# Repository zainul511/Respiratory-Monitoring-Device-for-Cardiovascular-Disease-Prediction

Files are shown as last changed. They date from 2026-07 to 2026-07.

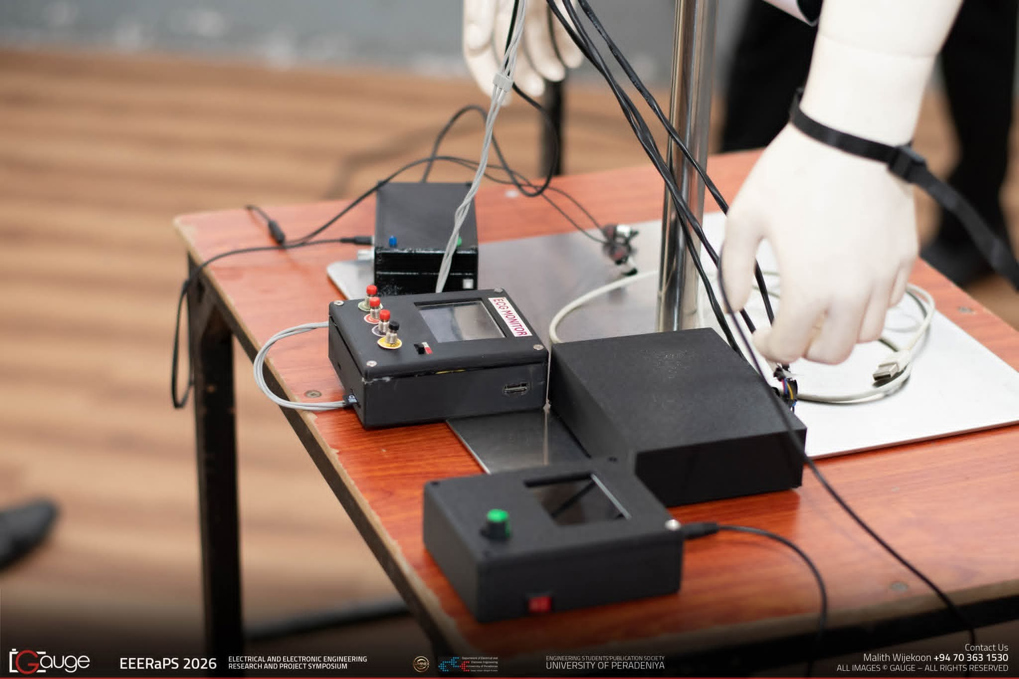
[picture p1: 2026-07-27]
Images/d04af45d-ff1c-4c60-89cd-eda54e68bfce.jpg

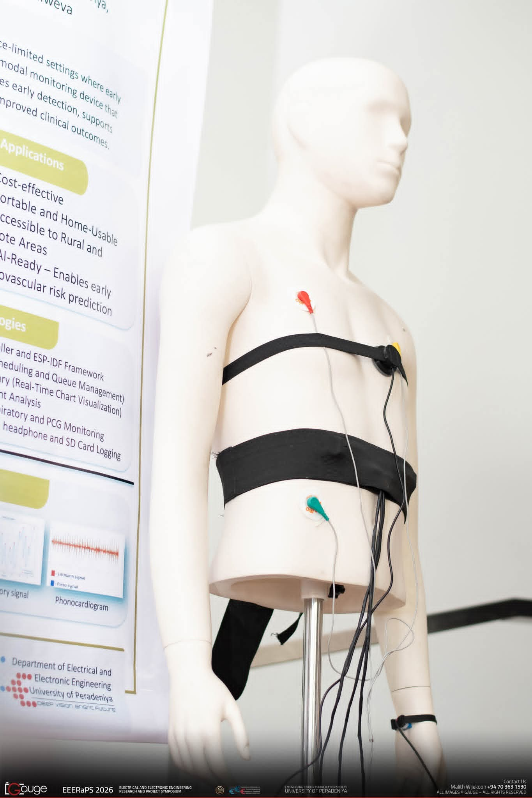
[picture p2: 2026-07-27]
Images/b8c4e4b6-da23-4e0d-b906-4e107dbe2d85.jpg

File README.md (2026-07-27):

# Respiratory-Monitoring-Device-for-Cardiovascular-Disease-Prediction
Wearable respiratory monitor using ESP32 &amp; 3x MPU6050s. Extracts  breathing patterns via Incremental PCA &amp; DMP signal fusion. Includes ESP-IDF firmware (Dual I2C), Code for Python dashboard (PyQt5), and 3D mechanical files for real-time cardiovascular analysis.

##  System Architecture

The device measures chest expansion and contraction using three strategically placed IMUs on a wearable belt. The system is designed to provide  respiratory pattern data through sensor fusion and advanced software processing.

### Key Features
* **Multi-Sensor Fusion:** Utilizes three **MPU6050** accelerometers to capture chest wall movement.
* **Real-Time Visualization:** A  **Python dashboard (PyQt5)** plots breathing waveforms and give visual analysis of respiratory patterns.
* **Advanced Signal Processing:**
    * **Incremental PCA (Principal Component Analysis):** Extracts the dominant breathing motion vector from the 3-axis acceleration data.
    * **EMA (Exponential Moving Average):** Applies smoothing filters to eliminate high-frequency noise and jitter.
* **Wearable Design:** A stretchable belt with  a custom 3D-printed enclosure

## Components Used

| Component | Quantity | Description |
|---|:---:|---|
| ESP32 Development Board | 1 | Main microcontroller (originally ESP32-C3). |
| MPU6050 Sensors | 3 | 6-axis accelerometer/gyroscope modules. |
| Elastic Belt | 1 | 1.5-inch wide stretchable belt with a side-release buckle. |
| JST Connectors | 3 | Detachable connectors for sensor connections. |
| Heat Shrink Tube | – | 1.2 cm diameter tubing for wire insulation and cable management. |
| 3.7 V Li-Po Battery | 1 | Rechargeable lithium-polymer battery for portable power. |
| Boost Converter | 1 | Steps up the battery voltage to the required system voltage. |
| 3.3 V Voltage Regulator | 1 | Provides a stable 3.3 V supply for the ESP32 and sensors. |
| Slide Switch | 1 | Main power ON/OFF switch for the device. |

## 3D Printed Parts

The following custom 3D-printed parts were designed for the wearable system:

- **Enclosure_Box.stl** – Houses the ESP32-C3 and connectors. Includes cutouts for the USB-C port, JST connectors, and the power switch/push button.
- **Bend_on_Belt.stl** – A belt-mounted cable guide that routes sensor wires securely and reduces mechanical stress during movement.

## Technical Implementation

### 1. Sensor Placement & Assembly

- **Three MPU6050 IMUs** are mounted on the elastic belt for respiratory motion sensing.
- **One IMU** is positioned centrally below the chest.
- **Two IMUs** are positioned symmetrically on the left and right sides of the central sensor.
- The sensors are connected using **12 signal lines**:
  - VCC × 3
  - GND × 3
  - SDA × 3
  - SCL × 3
- All wiring is bundled into a **stable cable harness** using heat-shrink tubing to improve mechanical strength, reduce cable movement, and enhance reliability during wearable operation.

## 2. Firmware (ESP-IDF + FreeRTOS)

The firmware is developed using **ESP-IDF** with **FreeRTOS**, providing deterministic task scheduling and reliable acquisition of respiratory motion data from three MPU6050 IMUs at **100 Hz**.

### Method 1 – I²C Multiplexer Architecture

This implementation uses a **PCA9548A I²C multiplexer** to interface with three MPU6050 sensors that all operate at the default **0x68** I²C address. The ESP32 selects the required multiplexer channel before communicating with each sensor.

| Sensor | PCA9548A Channel | I²C Address |
|---|---:|---:|
| IMU 1 | 0 | 0x68 |
| IMU 2 | 1 | 0x68 |
| IMU 3 | 2 | 0x68 |

**Features**
- Single ESP32 hardware I²C bus
- PCA9548A resolves address conflicts
- Sequential sensor polling at **100 Hz**
- Data transmitted to the PC via USB Serial as structured packets

---

### Method 2 – Dual I²C Bus Architecture

This implementation eliminates the external multiplexer by utilizing the ESP32's **two independent hardware I²C controllers**. One bus interfaces with a single MPU6050, while the second bus connects to two MPU6050 sensors configured with different addresses (**0x68** and **0x69**) using the AD0 pin.

| ESP32 I²C Bus | Connected Sensors | I²C Address(es) |
|---|---|---|
| I²C Bus 0 | IMU 1 | 0x68 |
| I²C Bus 1 | IMU 2, IMU 3 | 0x68, 0x69 |

**Features**
- No external I²C multiplexer required
- Reduced hardware complexity and wiring
- Uses both ESP32 hardware I²C peripherals
- **Utilizes the MPU6050 Digital Motion Processor (DMP) for onboard sensor fusion**
- **Obtains gravity-compensated linear acceleration directly from the DMP, reducing software processing on the ESP32**
- Improved signal quality by removing the gravity component before transmission
- Data acquired at **100 Hz** and transmitted via USB Serial as structured packets

## 3. PC Software (Python Dashboard)

The desktop application performs real-time data acquisition, signal processing, visualization, and data logging.

### Data Acquisition

- Reads real-time sensor data from the ESP32 through **USB Serial communication** (`COMx` on Windows).
- Receives linear acceleration data from the three MPU6050 IMU sensors.

### Signal Processing Pipeline

1. **Dimensionality Reduction**
   - Applies **Incremental Principal Component Analysis (IPCA)** to combine 3-axis acceleration data into a single dominant respiratory motion vector.

2. **Signal Smoothing**
   - Uses an **Exponential Moving Average (EMA)** filter to reduce high-frequency noise and improve waveform stability.

3. **Waveform Preservation**
   - Applies a **Besel filter** to remove unwanted frequency components while preserving the respiratory waveform characteristics.

4. **Displacement Estimation**
   - Performs double integration of filtered acceleration data to estimate chest displacement.
   - A low-pass filter(cutoff 0.2Hz) is applied before integration to reduce low-frequency drift caused by sensor bias and integration errors.

### Output

- Real-time visualization of:
  - Respiratory effort waveform
  - Estimated chest displacement waveform

- CSV data logging:
  - Linear acceleration values
  - Extracted respiratory waveform
  - Estimated displacement waveform

 ## Development Challenges & Solutions

### MPU6050 Communication Failure

**Problem:**
- One MPU6050 sensor powered on correctly but failed to transmit data.

**Investigation:**
- Continuity testing revealed a microscopic solder bridge between the pull-up resistors.
- The SDA line was unintentionally shorted to VCC.

**Solution:**
- Removed excess solder and verified the I2C communication.
- The sensor returned to normal operation.

**Lesson Learned:**
- Always verify sensor module connections and perform continuity checks before final assembly.

##  Author

This project was developed as part of an undergraduate final-year engineering project.

- **Subsystem:** Wearable Respiratory Effort Monitoring Device  
- **Main Project:** Pulse-Based Diagnosis System for Cardiovascular Disease Prediction

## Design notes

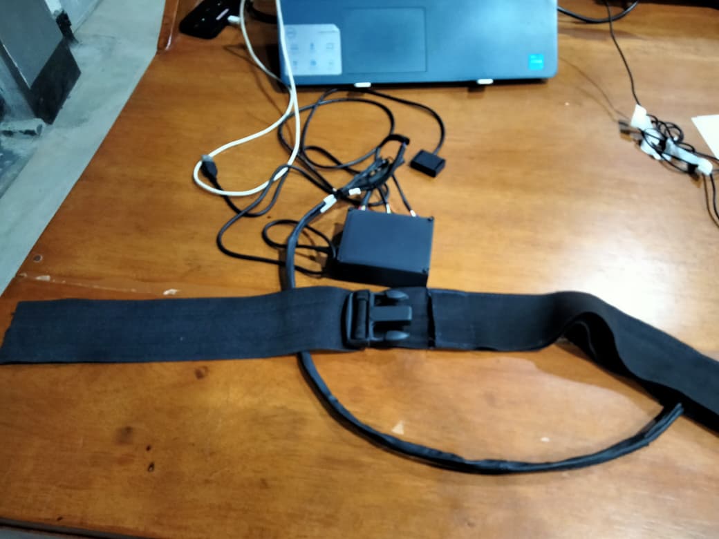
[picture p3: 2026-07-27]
Images/Product.jpeg

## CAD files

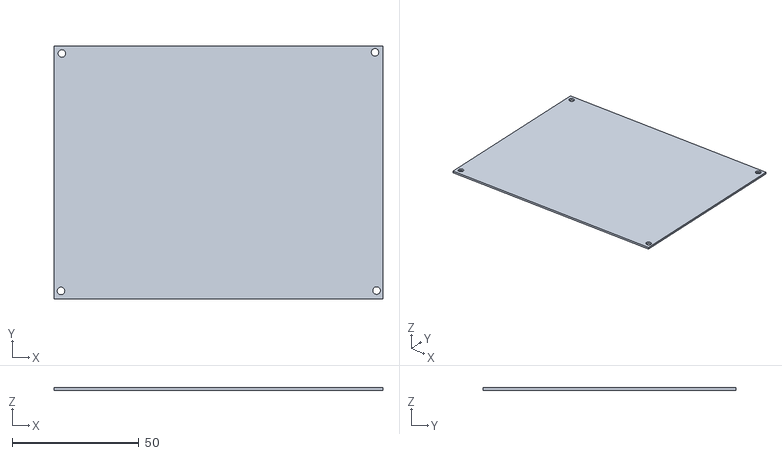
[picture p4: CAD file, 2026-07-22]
3D Printed Parts/lid_of_enclosure_box.stl
130.0 x 100.0 x 1.00

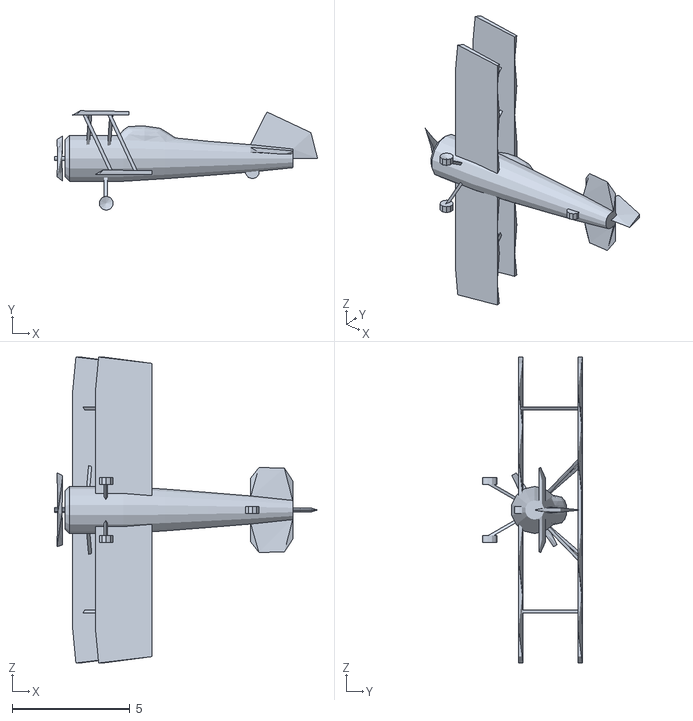
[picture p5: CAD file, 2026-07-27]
Firmware/V1_multiplexer/hello_world/i2cdevlib/Arduino/MPU6050/examples/MPU6050_DMP6_using_DMP_V6.12/MPUplane/data/biplane.obj
11.2 x 4.23 x 13.0

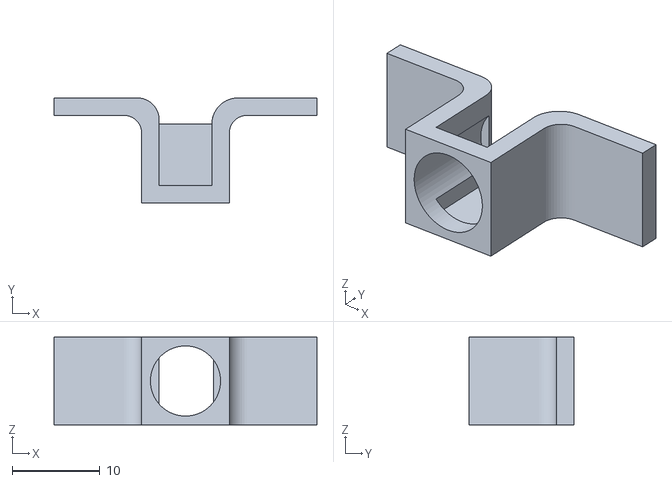
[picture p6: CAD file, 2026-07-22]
3D Printed Parts/Bend_on_Belt.stl
30.0 x 12.0 x 10.0

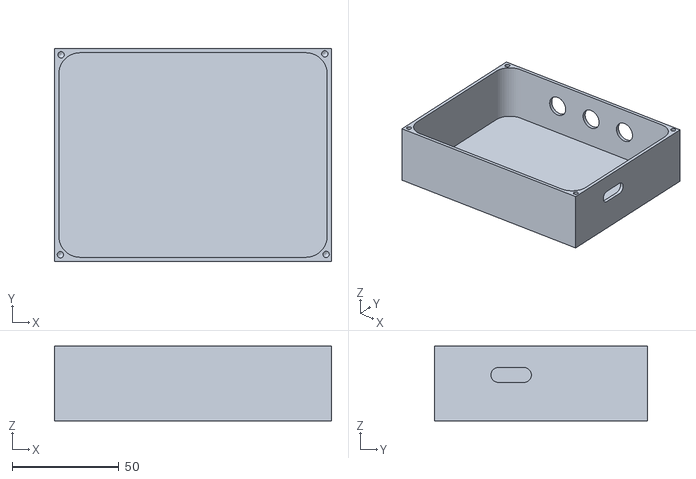
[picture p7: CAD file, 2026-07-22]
3D Printed Parts/Enclosure_Box.stl
130.0 x 100.0 x 35.0

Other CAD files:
Firmware/V1_multiplexer/hello_world/i2cdevlib/PIC18/MPU6050/Examples/MPU6050_raw.X/l.obj

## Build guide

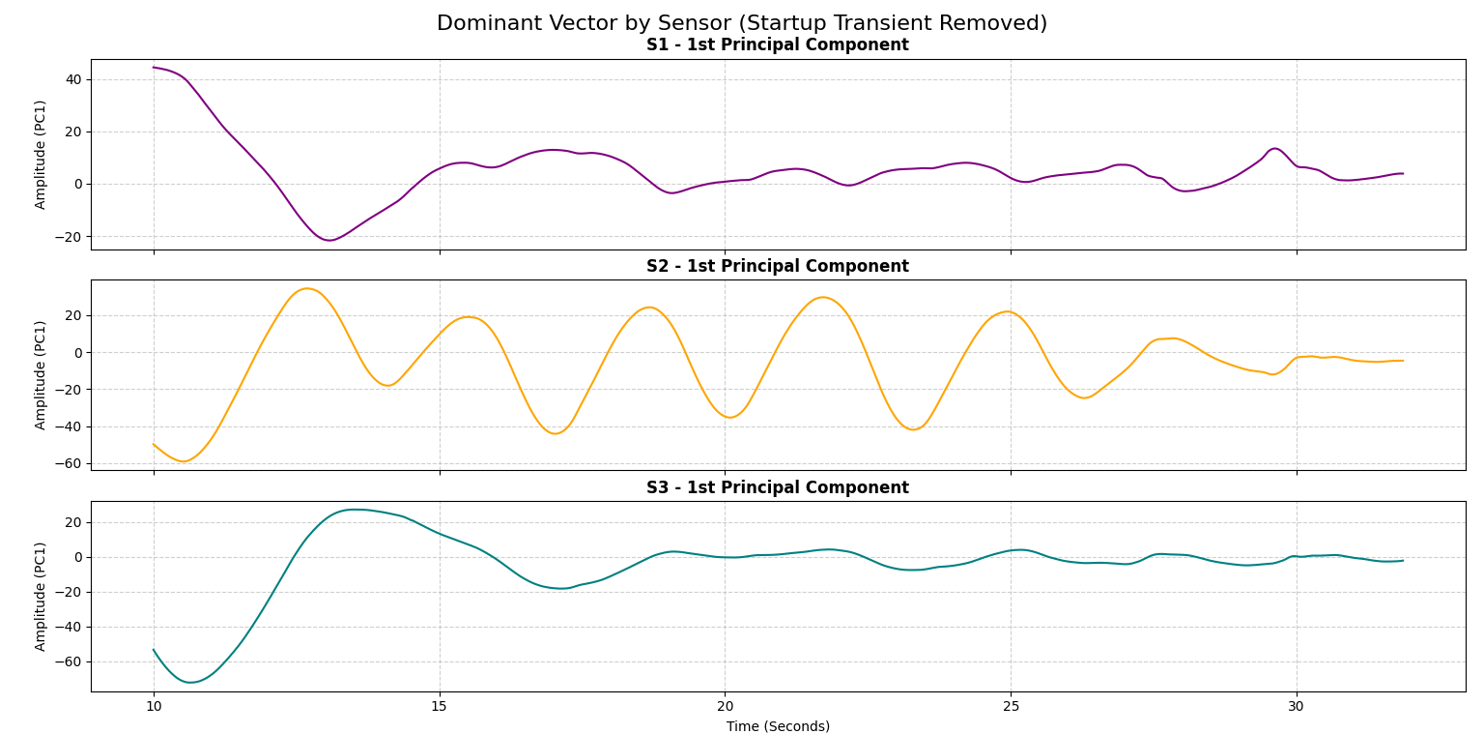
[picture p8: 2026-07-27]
Observations/reconstructed_after_pca.png

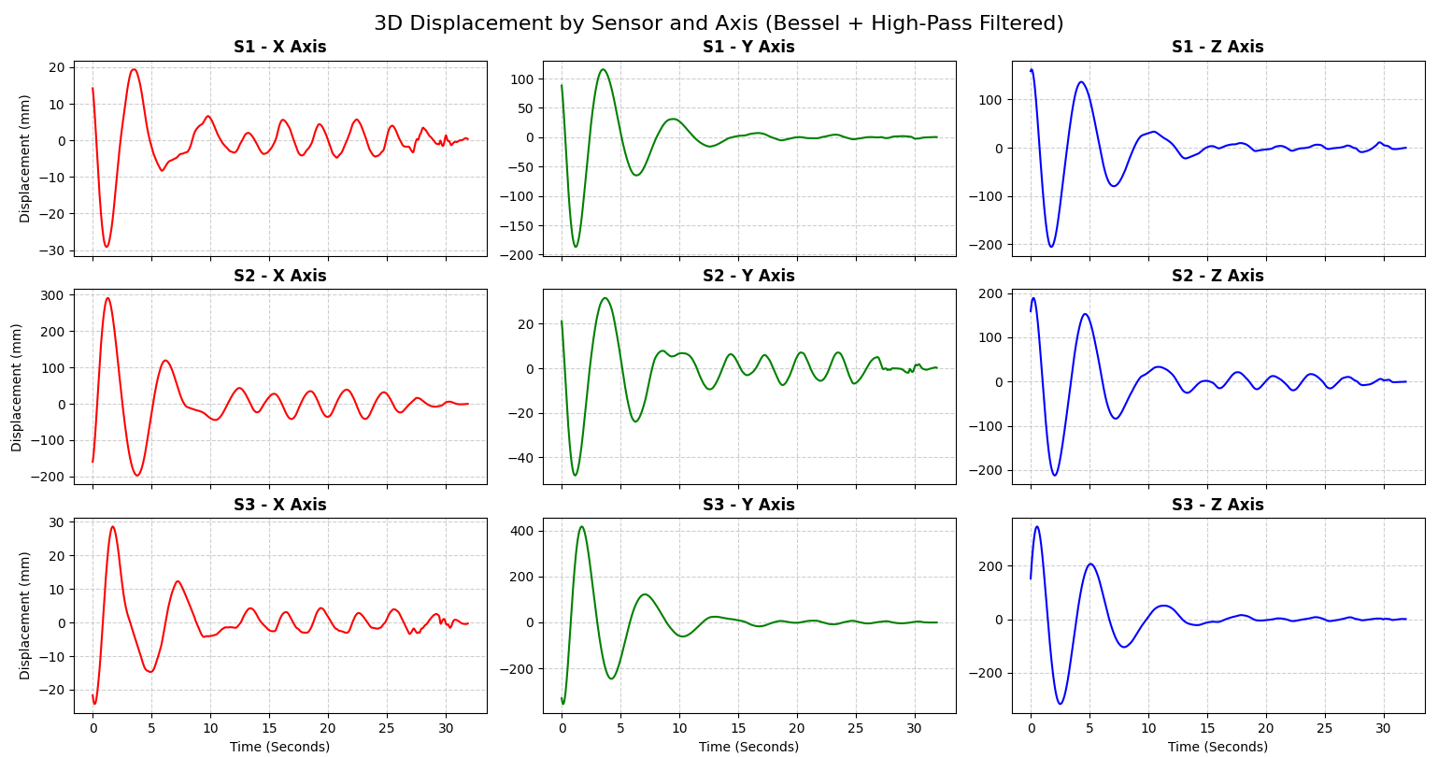
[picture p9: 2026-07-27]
Observations/reconstructed_waveform.png

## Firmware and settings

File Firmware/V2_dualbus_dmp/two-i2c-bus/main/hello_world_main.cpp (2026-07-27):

#include <stdio.h>
#include "freertos/FreeRTOS.h"
#include "freertos/task.h"
#include "driver/i2c.h"
#include "driver/gpio.h"
#include "esp_log.h"
#include "esp_timer.h"
#include "I2Cdev.h"
#include "MPU6050_6Axis_MotionApps20.h"

// --- Pin Definitions ---
#define I2C0_SDA_IO 21
#define I2C0_SCL_IO 22
#define I2C1_SDA_IO 25
#define I2C1_SCL_IO 27
#define SYNC_PIN 4
#define I2C_FREQ_HZ 400000 // 100kHz for Standard Mode



static const char *TAG = "MPU_TRIO"; // Tag for logging

//Struct to hold sensor data
struct SensorData {
    int16_t ax, ay, az; // Accelerometer data
    int16_t gx, gy, gz; // Gyroscope data
};

struct MPUOffsets { // Structure to hold offset values for each sensor
    int ax,ay,az; // Accelerometer offsets
    int gx,gy,gz; // Gyroscope offsets
};

// Offsets for each sensor (True Values)
MPUOffsets offsets_S1 = {-3478, -387, 896, 139, 8, -32};
MPUOffsets offsets_S2 = {290, -4953, 1866, 104, 49, -40};
MPUOffsets offsets_S3 = {-3534, -977, 1266, 50, -8, -38};

// Sensor Objects
MPU6050 mpu1(0x68); // Will use Bus 0
MPU6050 mpu2(0x69); // Will use Bus 0
MPU6050 mpu3(0x68); // Will use Bus 1 

// Global Buffers and Variables
uint8_t fifoBuffer[64]; // FIFO buffer for Accelerometer and Gyro . Static Array of 64 unsigned bytes
Quaternion q; // [w, x, y, z]         quaternion container 
VectorFloat gravity; // [x, y, z]        gravity vector
VectorInt16 aa, aaReal, gyro; //aa = [x, y, z]            accel sensor measurements
                             //aaReal = [x, y, z]        gravity-free accel sensor measurements
                             //gyro = [x, y, z]          gyro sensor measurements

// Standard I2C Init (Same as before)
void init_i2c_buses() {
    i2c_config_t conf0 = {};
    conf0.mode = I2C_MODE_MASTER;
    conf0.sda_io_num = (gpio_num_t)I2C0_SDA_IO;
    conf0.scl_io_num = (gpio_num_t)I2C0_SCL_IO;
    conf0.sda_pullup_en = GPIO_PULLUP_ENABLE;
    conf0.scl_pullup_en = GPIO_PULLUP_ENABLE;
    conf0.master.clk_speed = I2C_FREQ_HZ;
    i2c_param_config(I2C_NUM_0, &conf0);
    i2c_driver_install(I2C_NUM_0, conf0.mode, 0, 0, 0);

    i2c_config_t conf1 = {};
    conf1.mode = I2C_MODE_MASTER;
    conf1.sda_io_num = (gpio_num_t)I2C1_SDA_IO;
    conf1.scl_io_num = (gpio_num_t)I2C1_SCL_IO;
    conf1.sda_pullup_en = GPIO_PULLUP_ENABLE;
    conf1.scl_pullup_en = GPIO_PULLUP_ENABLE;
    conf1.master.clk_speed = I2C_FREQ_HZ;
    i2c_param_config(I2C_NUM_1, &conf1);
    i2c_driver_install(I2C_NUM_1, conf1.mode, 0, 0, 0);
}

// Helper to init DMP
void init_sensor_dmp(MPU6050 &mpu, const char* name, MPUOffsets offsets) { 
    mpu.initialize();

    ESP_LOGI(TAG, "Applying offsets for %s...", name);
    mpu.setXAccelOffset(offsets.ax);
    mpu.setYAccelOffset(offsets.ay);
    mpu.setZAccelOffset(offsets.az);
    mpu.setXGyroOffset(offsets.gx);
    mpu.setYGyroOffset(offsets.gy);
    mpu.setZGyroOffset(offsets.gz);

    if (mpu.testConnection() && mpu.dmpInitialize() == 0) { //Check mpu6050 connection and DMP is active.Send a small code chunk to DMP and it will reply with a status of zero if it is working properly
        mpu.setDMPEnabled(true); //Enable the DMP
        ESP_LOGI(TAG, "%s DMP Ready!", name); //Success Message
    } else {
        ESP_LOGE(TAG, "%s DMP Failed", name);
    }
}

// Helper to read and process DMP data (Compatible with older libraries)
// Check the sensor's FIFO buffer is in valid state and read data.
bool read_dmp_data(MPU6050 &mpu, SensorData &data, const char* name) {
    uint16_t fifoCount = mpu.getFIFOCount();

    // Check for FIFO overflow (Buffer size is 1024 bytes)
    if (fifoCount == 1024) {
        mpu.resetFIFO();
        return false; // Indicate overflow occurred
    }

    // A standard DMP packet is 42 bytes. Wait until we have at least one full packet.
    // Why DMP packet is 42 bytes: Quaternion (16) + Gyro (6) + Accel (6) + others (14) = 42 bytes.
    //What are the "others"? Temperature, Timestamp, etc.
    if (fifoCount >= 42) {
        // Read exactly 42 bytes from the FIFO buffer
        mpu.getFIFOBytes(fifoBuffer, 42);

        // Process the data
        mpu.dmpGetQuaternion(&q, fifoBuffer);
        mpu.dmpGetGravity(&gravity, &q);
        mpu.dmpGetAccel(&aa, fifoBuffer);
        mpu.dmpGetLinearAccel(&aaReal, &aa, &gravity);
        mpu.dmpGetGyro(&gyro, fifoBuffer);
        
        // Store into the passed structure 
        data.ax = aaReal.x;
        data.ay = aaReal.y;
        data.az = aaReal.z;
        data.gx = gyro.x;
        data.gy = gyro.y;
        data.gz = gyro.z;
        return true; // Indicate successful read
    }
    return false; // Not enough data yet
}

extern "C" void app_main(void) {
    init_i2c_buses();

    // Initialize SYNC_PIN as input to read sync signal
    gpio_reset_pin((gpio_num_t)SYNC_PIN); // Reset the pin to default state
    gpio_set_direction((gpio_num_t)SYNC_PIN, GPIO_MODE_INPUT); // Set as input to read the sync signal from external source (Aaftabs 10Hz Pulse Generator)
    // Force the pin to read 0 when unconnected
    gpio_set_pull_mode((gpio_num_t)SYNC_PIN, GPIO_PULLDOWN_ONLY);

    vTaskDelay(pdMS_TO_TICKS(100)); //PpdMS means "port delay in milliseconds". Why this delay? To give some time for the I2C buses to stabilize before we start communicating with the sensors. 
                                    //It's a common practice to add a small delay after initializing hardware components.


    ESP_LOGI(TAG, "--- INITIALIZING SENSORS ---");

    // 1. Switch to Bus 0 -> Initialize S1 and S2
    I2Cdev::setI2CPort(I2C_NUM_0);
    init_sensor_dmp(mpu1, "S1", offsets_S1);
    init_sensor_dmp(mpu2, "S2", offsets_S2);

    // 2. Switch to Bus 1 -> Initialize S3
    I2Cdev::setI2CPort(I2C_NUM_1);
    init_sensor_dmp(mpu3, "S3", offsets_S3);

    ESP_LOGI(TAG, "--- STARTING DATA STREAMING ---");
    // Print CSV Header
    printf("Time_ms,S1_Ax,S1_Ay,S1_Az,S1_Gx,S1_Gy,S1_Gz,S2_Ax,S2_Ay,S2_Az,S2_Gx,S2_Gy,S2_Gz,S3_Ax,S3_Ay,S3_Az,S3_Gx,S3_Gy,S3_Gz,Sync\n");

    SensorData d1, d2, d3; // Structures to hold data for each sensor
    bool got_s1, got_s2, got_s3; // Flags to indicate if we successfully read data from each sensor

    while (1) {

        int syncState = gpio_get_level((gpio_num_t)SYNC_PIN); // Read the current state of the sync pin (0 or 1)
                                                                // Once per loop, we read the Sync Pin

        // --- READ BUS 0 ---
        I2Cdev::setI2CPort(I2C_NUM_0);
        got_s1 = read_dmp_data(mpu1, d1, "S1"); // Read data from Sensor 1. This will check if there's a full DMP packet in the FIFO, read it, process it, and store the results in d1. It returns true if successful.
        got_s2 = read_dmp_data(mpu2, d2, "S2");



        // --- READ BUS 1 ---
        I2Cdev::setI2CPort(I2C_NUM_1);
        got_s3 = read_dmp_data(mpu3, d3, "S3");

        if (got_s1 && got_s2 && got_s3) { // Only print if we got valid data from all sensors
            uint32_t time_ms = esp_timer_get_time() / 1000; // Time in Milliseconds

            // Print formatted string: Time, S1(6 vals), S2(6 vals), S3(6 vals), Sync
            printf("%lu,%d,%d,%d,%d,%d,%d,%d,%d,%d,%d,%d,%d,%d,%d,%d,%d,%d,%d,%d\n",
                   time_ms,
                   d1.ax, d1.ay, d1.az, d1.gx, d1.gy, d1.gz,
                   d2.ax, d2.ay, d2.az, d2.gx, d2.gy, d2.gz,
                   d3.ax, d3.ay, d3.az, d3.gx, d3.gy, d3.gz,
                   syncState);
        }
        // Poll at 100Hz (10ms) - I set DMP output rate to 100Hz during initialization.
        vTaskDelay(pdMS_TO_TICKS(10));  //pdMS_TO_TICKS converts milliseconds to ticks based on FreeRTOS tick rate.
                                        // 1ms ==> 1 tick if tick rate is 1000Hz.
                                        // How we know tick rate? It's defined in FreeRTOSConfig.h as configTICK_RATE_HZ
                                        //Can we change tick rate? Yes, but be careful as it affects timing across the entire RTOS.
    }
}

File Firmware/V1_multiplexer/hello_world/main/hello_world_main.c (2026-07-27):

#include <stdio.h>
#include <inttypes.h>
#include <string.h>
#include "freertos/FreeRTOS.h"
#include "freertos/task.h"
#include "freertos/queue.h"
#include "driver/i2c.h"
#include "driver/gpio.h"
#include "esp_log.h"
#include "esp_timer.h"
#include "nvs_flash.h"
#include <MPU6050.h>

#define PCA9548A_ADDR 0x70
#define MPU6050_ADDR 0x68
#define MPU6050_WHO_AM_I 0x75
#define MPU6050_PWR_MGMT_1 0x6B
#define MPU6050_ACCEL_XOUT_H 0x3B

// ESP-C3 specific pin assignments
#define I2C_MASTER_SCL_IO 2
#define I2C_MASTER_SDA_IO 3
#define I2C_MASTER_FREQ_HZ 100000
#define I2C_MASTER_PORT I2C_NUM_0

static const char *TAG = "MPU6050";

// Queue to hold sensor data for serial output
static QueueHandle_t serial_queue;

typedef struct {
    int16_t accel[3][3]; // [sensor][x,y,z]
    int64_t timestamp_ms;
} sensor_packet_t;

// I2C initialization
void i2c_master_init() {
    i2c_config_t conf = {
        .mode = I2C_MODE_MASTER,
        .sda_io_num = I2C_MASTER_SDA_IO,
        .scl_io_num = I2C_MASTER_SCL_IO,
        .sda_pullup_en = GPIO_PULLUP_ENABLE,
        .scl_pullup_en = GPIO_PULLUP_ENABLE,
        .master.clk_speed = I2C_MASTER_FREQ_HZ,
    };
    i2c_param_config(I2C_MASTER_PORT, &conf);
    i2c_driver_install(I2C_MASTER_PORT, conf.mode, 0, 0, 0);
}

// PCA9548A channel selection
esp_err_t pca9548a_select_channel(uint8_t channel) {
    i2c_cmd_handle_t cmd = i2c_cmd_link_create();
    i2c_master_start(cmd);
    i2c_master_write_byte(cmd, (PCA9548A_ADDR << 1) | I2C_MASTER_WRITE, true);
    i2c_master_write_byte(cmd, (1 << channel), true);
    i2c_master_stop(cmd);
    esp_err_t ret = i2c_master_cmd_begin(I2C_MASTER_PORT, cmd, 100 / portTICK_PERIOD_MS);
    i2c_cmd_link_delete(cmd);
    return ret;
}

// I2C write
esp_err_t i2c_write_byte(uint8_t channel, uint8_t reg_addr, uint8_t data) {
    if (pca9548a_select_channel(channel) != ESP_OK) return ESP_FAIL;

    i2c_cmd_handle_t cmd = i2c_cmd_link_create();
    i2c_master_start(cmd);
    i2c_master_write_byte(cmd, (MPU6050_ADDR << 1) | I2C_MASTER_WRITE, true);
    i2c_master_write_byte(cmd, reg_addr, true);
    i2c_master_write_byte(cmd, data, true);
    i2c_master_stop(cmd);
    esp_err_t ret = i2c_master_cmd_begin(I2C_MASTER_PORT, cmd, 100 / portTICK_PERIOD_MS);
    i2c_cmd_link_delete(cmd);
    return ret;
}

// I2C read
esp_err_t i2c_read_bytes(uint8_t channel, uint8_t reg_addr, uint8_t *data, size_t len) {
    if (pca9548a_select_channel(channel) != ESP_OK) return ESP_FAIL;

    i2c_cmd_handle_t cmd = i2c_cmd_link_create();
    i2c_master_start(cmd);
    i2c_master_write_byte(cmd, (MPU6050_ADDR << 1) | I2C_MASTER_WRITE, true);
    i2c_master_write_byte(cmd, reg_addr, true);
    i2c_master_start(cmd);
    i2c_master_write_byte(cmd, (MPU6050_ADDR << 1) | I2C_MASTER_READ, true);
    if (len > 1) {
        i2c_master_read(cmd, data, len - 1, I2C_MASTER_ACK);
    }
    i2c_master_read_byte(cmd, data + len - 1, I2C_MASTER_NACK);
    i2c_master_stop(cmd);
    esp_err_t ret = i2c_master_cmd_begin(I2C_MASTER_PORT, cmd, 100 / portTICK_PERIOD_MS);
    i2c_cmd_link_delete(cmd);
    return ret;
}

// MPU6050 initialization
esp_err_t mpu6050_init(uint8_t channel) {
    esp_err_t ret = i2c_write_byte(channel, MPU6050_PWR_MGMT_1, 0x00);
    if (ret != ESP_OK) return ret;

    uint8_t who_am_i;
    ret = i2c_read_bytes(channel, MPU6050_WHO_AM_I, &who_am_i, 1);
    if (ret != ESP_OK || who_am_i != 0x68) return ESP_ERR_NOT_FOUND;

    ESP_LOGI(TAG, "MPU6050 on channel %d initialized", channel);
    return ESP_OK;
}

// Read accelerometer
esp_err_t mpu6050_read_accel(uint8_t channel, int16_t *accel_x, int16_t *accel_y, int16_t *accel_z) {
    uint8_t data[6];
    esp_err_t ret = i2c_read_bytes(channel, MPU6050_ACCEL_XOUT_H, data, 6);
    if (ret != ESP_OK) return ret;

    *accel_x = (int16_t)((data[0] << 8) | data[1]);
    *accel_y = (int16_t)((data[2] << 8) | data[3]);
    *accel_z = (int16_t)((data[4] << 8) | data[5]);
    return ESP_OK;
}

// Function to send data via Serial port 
void send_serial_data(sensor_packet_t *packet) {
    printf("{\"sensor1\":{\"x\":%d,\"y\":%d,\"z\":%d},"
           "\"sensor2\":{\"x\":%d,\"y\":%d,\"z\":%d},"
           "\"sensor3\":{\"x\":%d,\"y\":%d,\"z\":%d},"
           "\"timestamp\":%lld}\n",
           packet->accel[0][0], packet->accel[0][1], packet->accel[0][2],
           packet->accel[1][0], packet->accel[1][1], packet->accel[1][2],
           packet->accel[2][0], packet->accel[2][1], packet->accel[2][2],
           packet->timestamp_ms);
}

// Task to send serial data
void serial_send_task(void *pvParameters) {
    sensor_packet_t packet;
    while (true) {
        if (xQueueReceive(serial_queue, &packet, portMAX_DELAY)) {
            send_serial_data(&packet);
        }
    }
}

// Data collection task
void data_collection_task(void *pvParameters) {
    int16_t accel_data[3][3];
    sensor_packet_t packet;

    while (true) {
        for (uint8_t channel = 0; channel < 3; channel++) {
            if (mpu6050_read_accel(channel, &accel_data[channel][0], 
                                            &accel_data[channel][1], 
                                            &accel_data[channel][2]) == ESP_OK) {
                ESP_LOGI(TAG, "Sensor %d - X: %6d, Y: %6d, Z: %6d",
                        channel, accel_data[channel][0], accel_data[channel][1], accel_data[channel][2]);
            }
        }
        memcpy(packet.accel, accel_data, sizeof(accel_data));
        packet.timestamp_ms = esp_timer_get_time() / 1000;

        // Send to serial queue
        xQueueSend(serial_queue, &packet, 0);
        
        vTaskDelay(100 / portTICK_PERIOD_MS); // 10 Hz
    }
}

void app_main(void) {
    ESP_ERROR_CHECK(nvs_flash_init());

    // Initialize Serial port
    ESP_LOGI(TAG, "Serial port ready for Python communication");

    // Initialize I2C
    i2c_master_init();
    ESP_LOGI(TAG, "I2C initialized");

    // Initialize MPU6050
    for (uint8_t channel = 0; channel < 3; channel++) {
        if (mpu6050_init(channel) != ESP_OK) {
            ESP_LOGE(TAG, "MPU6050 on channel %d initialization failed!", channel);
        }
    }

    // Create queue for serial output
    serial_queue = xQueueCreate(10, sizeof(sensor_packet_t));

    // Create tasks
    xTaskCreate(data_collection_task, "data_collection", 4096, NULL, 5, NULL);
    xTaskCreate(serial_send_task, "serial_send", 4096, NULL, 5, NULL);

    ESP_LOGI(TAG, "System ready. Data collection is always active");
    ESP_LOGI(TAG, "Data will be sent via serial port in JSON format");
}

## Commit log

2026-07-22 Add 3D printed parts section to README
    Added section for 3D printed parts with descriptions.
2026-07-22 Add 3D printed part models
    [Bend_on_Belt.stl, Enclosure_Box.stl, lid_of_enclosure_box.stl]
2026-07-27 Add technical implementation details to README
    Added a section on technical implementation detailing sensor placement and assembly for the wearable system.
2026-07-27 Enhance README with firmware implementation details
    Expanded the firmware section to include two methods for interfacing with MPU6050 sensors using I²C. Detailed features and advantages of each method are provided.
2026-07-27 Update firmware and project files
    [biplane.obj, l.obj]
